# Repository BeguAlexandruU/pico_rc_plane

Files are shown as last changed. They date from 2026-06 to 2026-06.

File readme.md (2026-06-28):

# Pico RC Plane — Wireless RC Aircraft with Onboard Autopilot

A complete RC aircraft control system built on Raspberry Pi Pico microcontrollers, featuring 2.4 GHz wireless control, onboard PID-based attitude stabilization, multi-sensor fusion, GPS telemetry, and a Python desktop ground control station.

---

## Table of Contents

1. [System Overview](#system-overview)
2. [Architecture](#architecture)
3. [Hardware Components](#hardware-components)
4. [Subsystem Descriptions](#subsystem-descriptions)
   - [Transmitter Controller](#transmitter-controller)
   - [Flight Controller](#flight-controller)
   - [Telemetry Receiver](#telemetry-receiver)
   - [Desktop Ground Station](#desktop-ground-station)
5. [Wireless Communication Protocol](#wireless-communication-protocol)
6. [Flight Control Algorithm (PID)](#flight-control-algorithm-pid)
7. [Sensor Fusion](#sensor-fusion)
8. [Installation and Setup](#installation-and-setup)
9. [Pin Reference](#pin-reference)
10. [Technical Specifications](#technical-specifications)
11. [Known Limitations](#known-limitations)

---

## System Overview

The system consists of four interconnected components operating across two physical devices (Pico microcontrollers) and a PC:

```
┌─────────────────┐    2.4 GHz RF    ┌──────────────────────┐
│   TRANSMITTER   │ ───────────────► │   FLIGHT CONTROLLER  │
│  (CircuitPython)│  RC commands     │    (MicroPython)     │
│  Raspberry Pi   │  28 bytes/packet │   Raspberry Pi Pico  │
│  Pico           │                  │                      │
│                 │                  │  IMU + GPS + Baro    │
└─────────────────┘                  │  Servos + ESC        │
                                     └──────────┬───────────┘
                                                │ telemetry
                                                │ (NRF24L01)
                                     ┌──────────▼───────────┐
                                     │  TELEMETRY RECEIVER  │
                                     │   (MicroPython)      │
                                     │   Raspberry Pi Pico  │
                                     └──────────┬───────────┘
                                                │ USB serial
                                                │ CSV stream
                                     ┌──────────▼───────────┐
                                     │   DESKTOP GCS        │
                                     │   (Python / PyQt5)   │
                                     │  Live display        │
                                     │  Recording & Replay  │
                                     └──────────────────────┘
```

**Project structure:**

```
pico_rc_plane/
├── transmitter/
│   ├── code.py                 
│   ├── boot.py
│   ├── state_control.py        mașină de stări MENU / FLY / USB
│   ├── input_module.py         citire joystickuri și butoane
│   ├── menu_module.py          interfață OLED SSD1306
│   ├── rc_controller.py        serializare și transmisie RF
│   ├── usb_hid_gamepad.py      emulare gamepad USB-HID
│   ├── hid_gamepad.py
│   └── test/
├── desktop_app/
│   ├── main.py                 
│   ├── app/
│   │   ├── gcs_window.py       fereastra principală QMainWindow
│   │   ├── core/
│   │   │   ├── models.py       TelemetryFrame dataclass
│   │   │   ├── serial_reader.py  cititor serial pe QThread
│   │   │   └── recorder.py     înregistrare și redare CSV
│   │   ├── ui/
│   │   │   ├── themes.py       stiluri QSS dark/light
│   │   │   ├── telemetry_panel.py  indicatoare cu praguri de alertă
│   │   │   ├── map_view.py     hartă Leaflet.js
│   │   │   ├── view_3d.py      vizualizare 3D PyQtGraph
│   │   │   └── charts.py       grafice telemetrie pyqtgraph
│   │   └── utils/
│   │       └── stl_loader.py   încărcare mesh STL
│   ├── plane_models/
│   │   └── pico_plane.stl
│   ├── telemetry_logs/
│   ├── test/
│   └── requirements.txt
├── flight_controller/
│   ├── lib/                    drivere: nRF24L01+, fuziune IMU, OLED
│   ├── main.py                 
│   ├── imu_module.py           citire GY-87, fuziune Madgwick
│   ├── gps_module.py           parser NMEA neblocant (NEO-6M)
│   ├── pid_controller.py       buclele de control PID
│   ├── servo_control.py        control servomotor
│   ├── motor_control.py        control ESC
│   └── nrf_module.py           recepție comenzi de control și transmisie telemetrie
└── telemetry_receiver/
    ├── lib/                    drivere: nRF24L01+
    ├── main.py                 
    └── nrf_module.py
```

---

## Architecture

### Communication Flow

| Link | Direction | Protocol | Rate | Payload |
|---|---|---|---|---|
| Transmitter → Flight Controller | RC Commands | NRF24L01, 250 kbps | ~50 Hz | 5 bytes |
| Flight Controller → Telemetry Receiver | Sensor Data | NRF24L01, 250 kbps | 5 Hz | 28 bytes |
| Telemetry Receiver → PC | CSV Serial | USB-CDC, 115200 baud | 5 Hz | ~60 bytes/line |

### Flight Control Loop

The flight controller runs a fixed-rate control loop at 100 Hz on the Raspberry Pi Pico (RP2040 @ 250 MHz):

```
┌─────────────────────────────────────────────────────────────────┐
│  100 Hz Control Loop (10 ms period)                             │
│                                                                 │
│  1. NRF receive → decode RC stick commands                      │
│  2. IMU update  → sensor fusion → roll, pitch, heading          │
│  3. PID update  → compute servo corrections (Stabilize mode)    │
│  4. GPS update  → parse NMEA, update lat/lon (non-blocking)     │
│  5. Sleep remaining time to maintain exactly 100 Hz             │
└─────────────────────────────────────────────────────────────────┘
```

---

## Hardware Components

### Transmitter (Controller Pico)

| Component | Part | Interface |
|---|---|---|
| Microcontroller | Raspberry Pi Pico (RP2040) | — |
| RF Module | nRF24L01+ | SPI0 |
| Joysticks | 2× dual-axis analog (4 ADC channels) | GP26–GP29 |
| Buttons | 8× digital inputs | GP2–GP7, GP14, GP15 |
| Display | SSD1306 OLED 128×64 | I2C (GP0 SDA, GP1 SCL) |
| Power Monitor | INA219 | I2C |

### Flight Controller Pico

| Component | Part | Interface |
|---|---|---|
| Microcontroller | Raspberry Pi Pico (RP2040) | — |
| RF Module | nRF24L01+ | SPI1 |
| IMU | MPU6050 (6-axis accel + gyro) | I2C1 |
| Magnetometer | QMC5883L (3-axis compass) | I2C1 |
| Barometer | BMP180 (pressure/altitude) | I2C1 |
| GPS | Generic UART NMEA module | UART0 |
| Motor ESC | Brushless ESC (PWM input) | GP28 |
| Aileron Left Servo | Analog servo | GP26 |
| Aileron Right Servo | Analog servo | GP27 |
| Elevator Servo | Analog servo | GP22 |

### Telemetry Receiver Pico

| Component | Part | Interface |
|---|---|---|
| Microcontroller | Raspberry Pi Pico (RP2040) | — |
| RF Module | nRF24L01+ | SPI0 |
| PC Link | USB serial (USB-CDC) | USB |

---

## Subsystem Descriptions

### Transmitter Controller

**File:** `controller/code.py`  
**Runtime:** CircuitPython

The transmitter implements a three-state machine:

| State | Description |
|---|---|
| `STATE_MENU` (0) | OLED menu for selecting operating mode |
| `STATE_FLY` (1) | Wireless RC transmission via NRF24L01 |
| `STATE_USB` (2) | USB HID gamepad emulation for ground testing |

In FLY mode, the main loop reads four analog joystick axes and eight digital buttons, packages the data into a 5-byte struct, and transmits at approximately 50 Hz. An ARM switch disables the throttle channel when disarmed, preventing accidental motor starts.

**Joystick Processing:**
- Raw ADC: 0–65535 (12-bit Pico ADC)
- Active range: 8000–58000
- Deadzone: ±2000 units around center (32768)
- Output: Throttle 0–255, all other axes −127 to +127

**Trim System:** Dedicated buttons incrementally adjust `trim_roll` and `trim_pitch` offsets that are added to stick values before transmission.

---

### Flight Controller

**File:** `flight_controller/main.py`  
**Runtime:** MicroPython  
**CPU:** RP2040 @ 250 MHz

#### Input Processing

The NRF module receives 5-byte RC command packets and exposes four channels as global variables:

| Variable | Type | Range | Control |
|---|---|---|---|
| `ch1_rudder` | int8 | −127 to +127 | (unused, future rudder) |
| `ch2_throttle` | uint8 | 0 to 255 | Motor throttle |
| `ch3_aileron` | int8 | −127 to +127 | Roll / aileron |
| `ch4_elevator` | int8 | −127 to +127 | Pitch / elevator |
| `fly_mode` | uint8 | 0 or 1 | Stabilize / Manual |

**Failsafe:** If no packet is received for 1000 ms, all channels are zeroed (throttle off, surfaces centered) and `fly_mode` is set to Stabilize.

#### Flight Modes

**Stabilize Mode (fly_mode = 0):**  
Stick deflection commands a target attitude angle (−80° to +80°). The PID controller computes the servo correction needed to reach and hold that angle. This provides self-leveling behavior — releasing the stick commands 0° (wings level).

**Manual Mode (fly_mode = 1):**  
Stick deflection maps directly to servo position with no attitude feedback. The pilot has direct control analogous to a conventional RC system.

#### Motor Control

The ESC is driven by a 50 Hz PWM signal on GP28:

| Throttle Value | Pulse Width | State |
|---|---|---|
| 0 | 1.0 ms | Armed, zero thrust |
| 128 | 1.5 ms | ~50% thrust |
| 255 | 2.0 ms | Full thrust |

#### Servo Control

Three servos control the flight surfaces. All use 0.5–2.5 ms pulse range (180° physical travel):

| Servo | Pin | Flight Limit |
|---|-----|---|
| Aileron Left | GP26 | ±30° |
| Aileron Right | GP27 | ±30° (mirrored, differential) |
| Elevator | GP22 | ±30° |

Differential aileron: `aileron_right.value = 1.0 - aileron_left.value` ensures that when the left aileron deflects down, the right deflects up, generating a rolling moment.

---

### Telemetry Receiver

**File:** `telemetry_receiver/main.py`  
**Runtime:** MicroPython

A minimal Pico dedicated to receiving the 28-byte telemetry packets from the flight controller and printing them as CSV lines to the USB serial port. The desktop app reads these lines at 115200 baud.

**Output format:**
```
roll,pitch,heading,altitude,gps_lat,gps_lon,timestamp_ms
```
Example: `-1.23,2.45,180.00,12.50,47.150476,27.636506,45230`

---

### Desktop Ground Station

**File:** `desktop_app/main.py`  
**Runtime:** Python 3.10+, PyQt5

A PyQt5 graphical application providing:

- **Live telemetry display** — numeric readouts for roll, pitch, heading, altitude, and GPS position with colour-coded alerts (amber at warning threshold, red at critical)
- **2D map view** — GPS flight track rendered on a Leaflet.js map inside a `QWebEngineView`, switchable between OpenStreetMap, Google Satellite, and Google Terrain
- **Full 3D view** — PyQtGraph OpenGL visualization of the aircraft model (STL) with real attitude applied via Euler rotation
- **CSV recording** — saves live telemetry to timestamped CSV files in `telemetry_logs/`
- **Replay system** — loads any saved log and replays it at correct real-time speed (computed from `timestamp_ms` differences between consecutive frames), with timeline slider, speed multiplier (0.5×–4×), and frame-accurate scrubbing
- **Analytics charts** — altitude and roll/pitch/yaw time-series charts populated on replay load

**Project structure:**
```
desktop_app/
├── main.py               entry point
├── app/
│   ├── gcs_window.py     main QMainWindow
│   ├── core/
│   │   ├── models.py     TelemetryFrame dataclass
│   │   ├── serial_reader.py  QThread serial reader
│   │   └── recorder.py   CSV read/write/list
│   ├── ui/
│   │   ├── themes.py     dark and light QSS stylesheets
│   │   ├── telemetry_panel.py  gauge widgets with alert colouring
│   │   ├── map_view.py   Leaflet.js map
│   │   ├── view_3d.py    PyQtGraph 3D view
│   │   └── charts.py     pyqtgraph analytics
│   └── utils/
│       └── stl_loader.py STL mesh loader
└── requirements.txt
```

---

## Wireless Communication Protocol

### NRF24L01 Common Configuration

| Parameter | Value |
|---|---|
| Frequency band | 2.4 GHz ISM |
| RF channel | 108 (2508 MHz) |
| Data rate | 250 kbps |
| Output power | 0 dBm (MAX) |
| Payload size | 28 bytes (fixed) |
| Auto-ACK | Disabled |
| CRC | 2 bytes |

### RC Command Packet — Transmitter → Flight Controller

**TX address:** `b"node2"` | **RX address:** `b"node2"`

```python
struct.pack("<bBbbB", ch1_rudder, ch2_throttle, ch3_aileron, ch4_elevator, fly_mode)
```

| Field | C Type | Range | Description |
|---|---|---|---|
| ch1_rudder | int8 | −127 to +127 | Channel 1 (unused) |
| ch2_throttle | uint8 | 0 to 255 | Throttle |
| ch3_aileron | int8 | −127 to +127 | Roll command |
| ch4_elevator | int8 | −127 to +127 | Pitch command |
| fly_mode | uint8 | 0 or 1 | 0 = Stabilize, 1 = Manual |

Total: 5 bytes active. Remaining 23 bytes are padding to reach the fixed 28-byte payload.

### Telemetry Packet — Flight Controller → Telemetry Receiver

**TX address:** `b"node3"` | **RX address:** `b"node3"`

```python
struct.pack("<ffffffI",
    roll, pitch, heading,
    relative_altitude,
    gps_lat, gps_lon,
    timestamp_ms)
```

| Field | C Type | Unit | Description |
|---|---|---|---|
| roll | float32 | degrees | Bank angle (−180 to +180) |
| pitch | float32 | degrees | Pitch angle (−90 to +90) |
| heading | float32 | degrees | Magnetic heading (0 to 360) |
| relative_altitude | float32 | metres | Altitude above takeoff point |
| gps_lat | float32 | decimal degrees | Latitude |
| gps_lon | float32 | decimal degrees | Longitude |
| timestamp_ms | uint32 | milliseconds | Time since boot |

Total: 6 × 4 + 4 = **28 bytes** exactly.

---

## Flight Control Algorithm (PID)

### Overview

The Stabilize flight mode uses two independent PID controllers — one for roll (aileron axis) and one for pitch (elevator axis). Each controller computes a servo correction signal in the range −127 to +127.

### Signal Chain

```
RC Stick (−127…+127)
        │
        ▼
  map_to_angle()          linear map: −127…+127 → −80°…+80°
        │
        ▼
  Target Angle (°)
        │
        ├─────────────────────────────────┐
        │                                 │
   setpoint                           measurement
        │                          (IMU fusion roll/pitch)
        └──────────► PID.compute() ◄─────┘
                          │
                          ▼
                  Servo Command (−127…+127)
                          │
                          ▼
               servo_control.set_aileron()
```

### PID Implementation

The controller implements **derivative-on-measurement** and **integral anti-windup**:

```python
# Proportional
p = Kp × error

# Integral with clamping (anti-windup)
integral += error × dt
integral  = clamp(integral, −integral_max, +integral_max)
I = Ki × integral

# Derivative on measurement (no derivative kick on setpoint change)
raw_d    = −(measurement − prev_measurement) / dt
d_filtered = α × raw_d + (1−α) × prev_d_filtered   # low-pass filter
D = Kd × d_filtered

output = clamp(P + I + D, −127, +127)
```

**Derivative-on-measurement** computes the derivative of the sensor reading rather than the error. When the pilot moves the stick, the setpoint changes instantaneously — computing the derivative of the error would produce a large spike (derivative kick). Since the measured angle changes smoothly, the derivative of the measurement remains bounded.

**Integral anti-windup** limits the accumulated integral to ±40 (separate from the output limits of ±127). This prevents the integrator from saturating the output when the aircraft is held in a sustained error state (e.g., during a large attitude change).

**Derivative low-pass filter** with coefficient α = 0.4 reduces the amplification of IMU quantization noise by the kd gain.

### Tuned Parameters

| Axis | Kp | Ki | Kd | integral_max | d_alpha |
|---|----|----|-----|---|---|
| Roll | 1.2 | 0.2 | 0.05 | 40 | 0.4 |
| Pitch | 1.0 | 0.1 | 0.05 | 40 | 0.4 |

---

## Sensor Fusion

### IMU — MPU6050

The MPU6050 provides 6-axis inertial data at up to 1 kHz. At the 100 Hz control loop rate, it supplies:
- 3-axis accelerometer (g-force, used to determine tilt via gravity vector)
- 3-axis gyroscope (deg/s, used for angular rate integration)

### Magnetometer — QMC5883L

The QMC5883L provides 3-axis magnetic field measurements used to compute absolute heading (0°–360°). A 20-second calibration routine at startup rotates the aircraft through a figure-8 pattern to determine hard-iron and soft-iron offsets.

### Sensor Fusion Algorithm

The Mahony/Madgwick-style 9-DOF fusion algorithm (`lib/fusion.py`) combines accelerometer, gyroscope, and magnetometer data to produce drift-free roll, pitch, and heading angles:
- **Gyroscope integration** provides fast, low-noise short-term angle tracking
- **Accelerometer** provides a gravity reference to correct gyroscope drift in roll and pitch
- **Magnetometer** provides an Earth's magnetic field reference to correct heading drift

### Barometer — BMP180

Relative altitude is computed from atmospheric pressure. A 5-sample baseline is averaged at startup. Subsequent readings are smoothed with an IIR low-pass filter:

```
altitude_filtered = 0.9 × altitude_prev + 0.1 × altitude_raw
```

This update runs at 20 Hz (every 5th control loop iteration) to stay within the BMP180's maximum conversion rate.

---

## Installation and Setup

### Prerequisites

- Python 3.10 or higher
- Two Raspberry Pi Pico boards (one for transmitter, one for flight controller)
- One additional Pico for the dedicated telemetry receiver (optional)

### Desktop Application

```bash
cd desktop_app
python -m venv .venv
# Windows
.venv\Scripts\activate
# macOS/Linux
source .venv/bin/activate

pip install -r requirements.txt
python main.py
```

**Dependencies:** `PyQt5`, `PyQtWebEngine`, `pyqtgraph`, `PyOpenGL`, `numpy`, `numpy-stl`, `pyserial`

### Transmitter (Controller Pico)

1. Flash **CircuitPython** to the Pico
2. Copy all files from `controller/` to the Pico drive
3. Install CircuitPython libraries: `circuitpython_nrf24l01`, `adafruit_ssd1306`, `adafruit_ina219`
4. `code.py` runs automatically on boot

### Flight Controller Pico

1. Flash **MicroPython** (v1.20+) to the Pico
2. Copy `flight_controller/` files and `lib/` directory to the Pico filesystem
3. Connect sensors to I2C1 (SDA=GP14, SCL=GP15)
4. Connect GPS UART to UART0 (RX=GP13)
5. `main.py` runs automatically on boot (100 Hz loop starts immediately)

### Telemetry Receiver Pico

1. Flash **MicroPython** to the Pico
2. Copy `telemetry_receiver/` files and `lib/` directory to the Pico
3. `main.py` runs automatically on boot; telemetry appears as CSV on USB serial

---

## Pin Reference

### Transmitter Pico (CircuitPython)

| Signal | Pin | Notes |
|---|-----|---|
| NRF24L01 SCK | GP10 | SPI0 |
| NRF24L01 MOSI | GP11 | SPI0 |
| NRF24L01 MISO | GP12 | SPI0 |
| NRF24L01 CSN | GP9 | — |
| NRF24L01 CE | GP8 | — |
| Joystick 1 X | GP27 | ADC |
| Joystick 1 Y | GP29 | ADC |
| Joystick 2 X | GP28 | ADC |
| Joystick 2 Y | GP26 | ADC |
| 8× Buttons | GP2–GP7, GP14, GP15 | Digital in |

### Flight Controller Pico (MicroPython)

| Signal | Pin | Notes |
|---|-----|---|
| NRF24L01 SCK | GP18 | SPI1 |
| NRF24L01 MOSI | GP19 | SPI1 |
| NRF24L01 MISO | GP16 | SPI1 |
| NRF24L01 CSN | GP17 | — |
| NRF24L01 CE | GP20 | — |
| IMU/Compass/Baro SDA | GP14 | I2C1 |
| IMU/Compass/Baro SCL | GP15 | I2C1 |
| GPS UART RX | GP13 | UART0 |
| GPS UART TX | GP12 | UART0 |
| Motor ESC PWM | GP28 | 50 Hz PWM |
| Aileron Left | GP26 | 50 Hz PWM |
| Aileron Right | GP27 | 50 Hz PWM |
| Elevator | GP22 | 50 Hz PWM |

### Sensor I2C Addresses

| Sensor | Address |
|---|---|
| MPU6050 | 0x68 |
| QMC5883L | 0x0D |
| BMP180 | 0x77 |

### Telemetry Receiver Pico (MicroPython)

| Signal | Pin | Notes |
|---|-----|---|
| NRF24L01 SCK | GP2 | SPI0 |
| NRF24L01 MOSI | GP3 | SPI0 |
| NRF24L01 MISO | GP4 | SPI0 |
| NRF24L01 CSN | GP1 | — |
| NRF24L01 CE | GP0 | — |

---

## Technical Specifications

| Parameter | Value |
|---|---|
| Control loop frequency | 100 Hz |
| Servo/ESC PWM frequency | 50 Hz |
| IMU update rate | 100 Hz |
| Barometer update rate | 20 Hz |
| GPS baud rate | 9600 baud (NMEA) |
| Telemetry output rate | 5 Hz |
| RF link latency | ~4 ms (SPI transfer) |
| RF channel | 108 (2508 MHz) |
| RF data rate | 250 kbps |
| RF payload size | 28 bytes (fixed) |
| Stick-to-angle mapping | ±127 stick → ±80° |
| Servo travel limit | ±30° (aileron and elevator) |
| Throttle range | 0–255 → 1.0–2.0 ms PWM |
| Failsafe timeout | 1000 ms |
| Desktop GCS update rate | 5 Hz (serial), 10 Hz (map), 60 Hz (3D) |

---

## Known Limitations

- **GPS accuracy:** float32 provides ~6 significant digits of coordinate precision, sufficient for visual tracking but not survey-grade positioning. GPS has no lock indicator in telemetry — `lat=0.0, lon=0.0` is transmitted until a valid NMEA fix is obtained.
- **Magnetometer heading:** Subject to magnetic interference from the motor, ESC, and battery. Positioning the compass away from high-current conductors is required for reliable heading data.
- **Single-axis PID:** Roll and pitch are controlled independently. Cross-coupling between axes (e.g., rudder-roll interaction) is not compensated.
- **No airspeed sensing:** The PID gains are tuned for a nominal airspeed. At very low or high airspeeds, control authority changes and the PID response will differ from the tuned behavior.
- **Barometric altitude:** Sensitive to local weather pressure changes. The baseline is sampled at startup; a pressure change of 1 hPa corresponds to approximately 8.5 m of apparent altitude change.
- **No return-to-home:** Loss of signal activates failsafe (throttle off, surfaces neutral) rather than autonomous return.

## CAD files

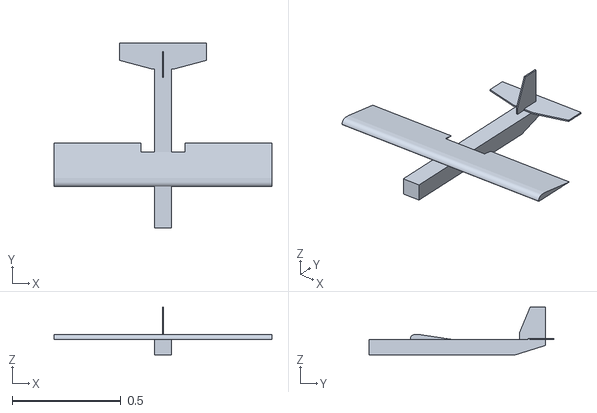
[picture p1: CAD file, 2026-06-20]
desktop_app/plane_models/pico_plane.stl
1.00 x 0.85 x 0.22

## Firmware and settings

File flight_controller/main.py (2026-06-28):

import imu_module
import nrf_module
import motor_control
import pid_controller
import servo_control
import gps_module
import utime
import machine

# ==== for me
# gpio 28
# gpio 27
# gpio 26
# gpio 22

machine.freq(250000000)

LOOP_FREQ = 100 # Hz
TARGET_PERIOD = 1_000_000 // LOOP_FREQ # microseconds

def setup():
    motor_control.setup()
    servo_control.setup()

    gps_module.setup()
    imu_module.setup()
    nrf_module.setup()
    pid_controller.setup()


setup()

_last_period_start = utime.ticks_us()
_loop_n = 0

while True:
    start_tick = utime.ticks_us()

    nrf_module.update()
    imu_module.update()
    pid_controller.update()
    gps_module.update()

    elapsed = utime.ticks_diff(utime.ticks_us(), start_tick)

    if elapsed < TARGET_PERIOD:
        utime.sleep_us(TARGET_PERIOD - elapsed)

    # # Măsoară perioada completă (muncă + sleep) după ce iterația s-a terminat.
    # # Printul este scos din fereastra de timp măsurată, deci nu distorsionează frecvența.
    # now = utime.ticks_us()
    # full_period = utime.ticks_diff(now, _last_period_start)
    # _last_period_start = now

    # _loop_n += 1
    # if _loop_n >= 50:
    #     freq = 1_000_000 / full_period if full_period > 0 else 0
    #     print(f"Freq: {freq:.1f} Hz  work: {elapsed} us / {TARGET_PERIOD} us", end="\r")
    #     _loop_n = 0

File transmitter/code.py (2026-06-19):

import state_control
import time
import input_module as controller
import usb_hid_gamepad as usb_gamepad
import rc_controller as rc_controller
import menu_module as menu_module


def setup():
    controller.setup()
    usb_gamepad.setup()
    rc_controller.setup()
    menu_module.setup()
    state_control.setup()

if __name__ == "__main__":
    
    setup()
    menu_module.change_menu(state_control.STATE_MENU)

    last_power_update = time.monotonic()

    while True:

        current_time = time.monotonic()
        if current_time - last_power_update >= 1.0:
            menu_module.update_power()
            last_power_update = current_time

        # 1. send messages
        if state_control.current_state == state_control.STATE_FLY:
            rc_controller.send_message()
            
        elif state_control.current_state == state_control.STATE_USB:
            usb_gamepad.send_usb_message()
                
        # 2. HANDLE BUTTON INPUT
        event = controller.keys.events.get()
        if event:
            if event.pressed:
                # event.key_number corresponds to the index in your 'pins' tuple
                if event.key_number == controller.BTN_A: # Button A
                    if state_control.current_state in (state_control.STATE_FLY, state_control.STATE_USB):
                        state_control.change_state(state_control.STATE_MENU)
                
                elif event.key_number == controller.BTN_B: # Button B
                    if state_control.current_state == state_control.STATE_MENU:
                        menu_module.menu_index = (menu_module.menu_index + 1) % 2
                        menu_module.menu_label.text = "> Fly Mode\n  USB Mode" if menu_module.menu_index == 0 else "  Fly Mode\n> USB Mode"
                        
                    if state_control.current_state == state_control.STATE_FLY: # Trim Pitch +
                        rc_controller.trim_pitch += 2
                        menu_module.trim_pitch_label.text = f"Trim Pitch: {rc_controller.trim_pitch}"

                elif event.key_number == controller.BTN_C: # Button C
                    if state_control.current_state == state_control.STATE_MENU:
                        new_state = state_control.STATE_FLY if menu_module.menu_index == 0 else state_control.STATE_USB
                        state_control.change_state(new_state)
                        
                    if state_control.current_state == state_control.STATE_FLY: # Trim Pitch -
                        rc_controller.trim_pitch -= 2
                        menu_module.trim_pitch_label.text = f"Trim Pitch: {rc_controller.trim_pitch}"
                
                elif event.key_number == controller.SW_ARM: # Switch ARM
                    if state_control.current_state == state_control.STATE_FLY:
                        menu_module.arm_label.text = "DISARMED"
                        rc_controller.armed = False
                        
                elif event.key_number == controller.BTN_LT: # Switch MODE
                    if state_control.current_state == state_control.STATE_FLY:
                        rc_controller.fly_mode = (rc_controller.fly_mode + 1) % 2
                        mode_text = "STABILIZE" if rc_controller.fly_mode == 0 else "MANUAL"
                        menu_module.mode_label.text = f"Mode: {mode_text}"
                        
                elif event.key_number == controller.BTN_RB: # Trim Roll +
                    if state_control.current_state == state_control.STATE_FLY:
                        rc_controller.trim_roll += 2
                        menu_module.trim_roll_label.text = f"Trim Roll: {rc_controller.trim_roll}"
                        
                elif event.key_number == controller.BTN_LB: # Trim Roll -
                    if state_control.current_state == state_control.STATE_FLY:
                        rc_controller.trim_roll -= 2
                        menu_module.trim_roll_label.text = f"Trim Roll: {rc_controller.trim_roll}"
                        
            elif event.released:
                if event.key_number == controller.SW_ARM: # Switch ARM
                    if state_control.current_state == state_control.STATE_FLY:
                        menu_module.arm_label.text = "ARMED"
                        rc_controller.armed = True

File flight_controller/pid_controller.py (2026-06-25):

import time
import nrf_module
import imu_module
import motor_control
import servo_control


class PID:
    def __init__(self, kp, ki, kd, output_limits=(-127, 127)):
        self.kp = kp
        self.ki = ki
        self.kd = kd
        self._limits = output_limits

        self.last_error = 0
        self._integral = 0
        self.last_time = time.ticks_ms()

    def reset_integral(self):
        self._integral = 0

    def compute(self, setpoint, actual, print_debug=False):
        now = time.ticks_ms()
        dt = time.ticks_diff(now, self.last_time) / 1000.0
        if dt <= 0: return self.last_error # Prevent division by zero

        error = setpoint - actual
        
        # Proportional
        p = self.kp * error
        
        # Integral
        self._integral += self.ki * error * dt
        self._integral = max(self._limits[0], min(self._limits[1], self._integral))
        
        # Derivative
        d = self.kd * (error - self.last_error) / dt
        
        output = p + self._integral + d
        
        # Apply limits (-127 to 127)
        output = max(self._limits[0], min(self._limits[1], output))
        
        self.last_error = error
        self.last_time = now

        if print_debug:
            print(f"PID Compute | Setpoint: {setpoint:.2f}, Actual: {actual:.2f}, Error: {error:.2f}, P: {p:.2f}, I: {self._integral:.2f}, D: {d:.2f}, Output: {output:.2f}")
        return output


ROLL_SLOPE = (80 - (-80)) / (127 - (-127))
roll_pid = None
pitch_pid = None

def setup():
    global roll_pid, pitch_pid
    roll_pid = PID(kp=1.2, ki=0, kd=0.05, output_limits=(-127, 127))
    pitch_pid = PID(kp=1.0, ki=0, kd=0.05, output_limits=(-127, 127))

def map_input_to_angle(x):
    # Simplified Formula: (x - in_min) * slope + out_min
    return (x + 127) * ROLL_SLOPE - 80

def update():
    if nrf_module.fly_mode == 0:  # Stabilize Mode
        # Convert NRF Stick (-127 to 127) to Target Angle (-80 to +80 degrees)
        target_roll = map_input_to_angle(nrf_module.ch3_aileron)
        target_pitch = map_input_to_angle(nrf_module.ch4_elevator)
        
        # Get Actual Angles from IMU
        current_roll = imu_module.fusion.roll
        current_pitch = imu_module.fusion.pitch

        if abs(nrf_module.ch2_throttle) < 10:
            roll_pid.reset_integral()
            pitch_pid.reset_integral()
        
        # Compute PID correction
        # The PID returns a value in the -127 to 127 range for your servo_control
        aileron_output = roll_pid.compute(target_roll, -current_roll)
        elevator_output = pitch_pid.compute(target_pitch, current_pitch)

        servo_control.set_aileron(aileron_output)
        servo_control.set_elevator(-elevator_output)

        motor_control.set_throttle(nrf_module.ch2_throttle)
    else:  # Manual Mode
        servo_control.set_aileron(nrf_module.ch3_aileron)
        servo_control.set_elevator(-nrf_module.ch4_elevator)
        motor_control.set_throttle(nrf_module.ch2_throttle)

    # print(f"Target Roll: {target_roll:.1f} | Current Roll: {current_roll:.1f} | Aileron Output: {aileron_output:.1f}")

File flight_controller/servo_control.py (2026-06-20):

from lib.picozero import Servo

# --- Configuration ---
# Pulse width range (in seconds) - typically covers 180 degrees total
MIN_PULSE_WIDTH = 0.5 / 1000    # 0.5ms (-90 physical degrees)
MAX_PULSE_WIDTH = 2.5 / 1000    # 2.5ms (+90 physical degrees)
PHYSICAL_RANGE = 180.0          # Total physical range of the servo

# Flight Control Limits
AILERON_MAX_ANGLE = 30  
AILERON_MIN_ANGLE = -30 
ELEVATOR_MAX_ANGLE = 30
ELEVATOR_MIN_ANGLE = -30

# Pins
AILERON_LEFT_PIN = 26
AILERON_RIGHT_PIN = 27
ELEVATOR_PIN = 22

aileron_right = None
aileron_left = None
elevator = None

def setup():
    global aileron_left, aileron_right, elevator
    
    # Initialize servos
    aileron_left = Servo(AILERON_LEFT_PIN, min_pulse_width=MIN_PULSE_WIDTH, max_pulse_width=MAX_PULSE_WIDTH)
    aileron_right = Servo(AILERON_RIGHT_PIN, min_pulse_width=MIN_PULSE_WIDTH, max_pulse_width=MAX_PULSE_WIDTH)
    elevator = Servo(ELEVATOR_PIN, min_pulse_width=MIN_PULSE_WIDTH, max_pulse_width=MAX_PULSE_WIDTH)
    
    center_all()

def map_input_to_servo(input_val, target_min_angle, target_max_angle):
    """
    Maps -127 to 127 input -> Target Angle -> Servo Value (0.0 to 1.0)
    """
    # 1. Map input (-127 to 127) to Target Angle (e.g., -30 to 30)
    # Formula: (val - in_min) * (out_range) / (in_range) + out_min
    angle = (input_val - (-127)) * (target_max_angle - target_min_angle) / (127 - (-127)) + target_min_angle
    
    # 2. Map Target Angle to Servo Value (0.0 - 1.0)
    # Assumes 0.0 = -90deg, 0.5 = 0deg, 1.0 = +90deg (Standard 180 throw)
    # Offset angle by +90 to align with 0-180 scale, then divide by total range
    servo_value = (angle + (PHYSICAL_RANGE / 2.0)) / PHYSICAL_RANGE
    
    return servo_value

def set_aileron(input_value): # -127 to 127
    global aileron_left, aileron_right
    
    # Calculate the normalized servo value (0.0 to 1.0) for the requested angle
    val = map_input_to_servo(input_value, AILERON_MIN_ANGLE, AILERON_MAX_ANGLE)
    
    aileron_left.value  = val
    aileron_right.value = val   # mirrored for differential aileron

def set_elevator(input_value): # -127 to 127
    global elevator
    
    # Calculate the normalized servo value (0.0 to 1.0) for the requested angle
    val = map_input_to_servo(input_value, ELEVATOR_MIN_ANGLE, ELEVATOR_MAX_ANGLE)
    
    elevator.value = val

def center_all():
    set_aileron(0)  
    set_elevator(0)
    

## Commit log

2026-02-05 fix joystick axis pins
    [input_module.py, usb_hid_gamepad.py]
2026-02-13 plane, add imu_module and nrf_module
2026-02-14 plane: add servo and motor control module
2026-02-14 plane: fix imu error
    [imu_module.py, main.py, nrf_module.py]
2026-02-14 controller: axis_map center fix
    [input_module.py]
2026-02-15 plane: update fail safe
    [nrf_module.py]
2026-02-15 plane: servo control from received data
2026-02-15 change control data format, add pid control
2026-02-15 plane: fix control range, fix failsafe parameters, update pid controller
    [main.py, nrf_module.py, pid_controller.py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]
2026-02-15 controller: x axis death zone
2026-03-09 plane: motor control, main loop timing, pid control
2026-03-09 plane: new pid
2026-03-11 plane: pid tunning
2026-04-09 controller: add power module
2026-04-12 app: add plane 3D model and shader
    [george-scaled-144.stl, lightning-scaled-144.stl, wildcat-scaled-144.stl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]
2026-04-13 fix and test telemetry via nrf
    [main.py, nrf_module.py, rc_controller.py]
2026-05-02 fix radio comm //// pretest2
    [nrf_module.py, rc_controller.py]
2026-05-18 add magnetometer -> use fusion9 + calibration | nrf payload +heading | relative altitude
2026-05-20 flight_controller: pid tunning, add integral factor, nrf_module rename chanels
2026-06-20 desktop app: rebuild
    [fw-190-scaled-144.stl, george-scaled-144.stl, lightning-scaled-144.stl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]
2026-06-20 flight controller: upgrade and bug fix
    [main.py, nrf_module.py, pid_controller.py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]
